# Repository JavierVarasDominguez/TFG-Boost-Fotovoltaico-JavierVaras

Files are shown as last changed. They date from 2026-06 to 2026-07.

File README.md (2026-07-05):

# Diseño y estudio de un convertidor DC-DC Boost para carga de vehículos eléctricos a partir de energía fotovoltaica

Repositorio asociado al Trabajo Fin de Grado:

**Diseño y estudio de un convertidor DC-DC Boost para carga de vehículos eléctricos a partir de energía fotovoltaica**
**Autor:** Javier Varas Domínguez
**Titulación:** Grado en Ingeniería Electrónica Industrial y Automática
**Universidad:** Universidad de Cantabria
**Tutor:** Francisco Javier Díaz Rodríguez
**Curso:** 2025/2026

---

## Descripción del proyecto

Este proyecto tiene como objetivo el diseño, simulación y validación de un convertidor DC-DC tipo Boost aplicado a un sistema de carga de baterías de vehículos eléctricos alimentado mediante energía fotovoltaica.

El sistema parte de una instalación fotovoltaica residencial de aproximadamente 2,4 kW, formada por seis módulos conectados en serie. La tensión generada por el campo fotovoltaico se eleva mediante un convertidor Boost hasta un nivel adecuado para la carga de baterías de vehículos eléctricos.

Además del diseño teórico del convertidor, se ha desarrollado un modelo de simulación en MATLAB/Simulink, se ha implementado un algoritmo MPPT basado en el método de perturbación y observación, y se ha construido un prototipo experimental a escala reducida controlado mediante ESP32S.

---

## Objetivos principales

* Diseñar un convertidor DC-DC tipo Boost para una aplicación fotovoltaica orientada a la carga de vehículos eléctricos.
* Dimensionar los principales componentes de la etapa de potencia.
* Simular el comportamiento del sistema en MATLAB/Simulink.
* Implementar un algoritmo MPPT para mejorar el aprovechamiento de la energía disponible.
* Diseñar y fabricar una PCB para el prototipo experimental.
* Validar el funcionamiento del sistema mediante un prototipo a escala reducida.

---

## Estructura del repositorio

```text
TFG-Boost-Fotovoltaico-JavierVaras/
│
├── Simulink_Matlab/
│   ├── 04_Simulaciones_Convertidor/
│   └── Prototipo/
│
├── Codigos_Control_ESP32/
│
├── KiCad_Prototipo/
│
├── Documentacion_TFG/

```

### Simulink_Matlab

Contiene los modelos de simulación desarrollados en MATLAB/Simulink.
Incluye las simulaciones del convertidor Boost, el funcionamiento con ciclo de trabajo fijo, la implementación del algoritmo MPPT y la validación del prototipo experimental.

### Codigos_Control_ESP32

Incluye los códigos utilizados para el control del prototipo mediante ESP32S.
Se recogen tanto las pruebas de generación PWM como la implementación del algoritmo MPPT.

### KiCad_Prototipo

Contiene los archivos relacionados con el diseño electrónico del prototipo.
Incluye el esquemático, el diseño de la PCB y los archivos necesarios para documentar la placa desarrollada.

### Documentacion_TFG

Carpeta destinada a recoger la memoria del Trabajo Fin de Grado y documentación complementaria.

### Resultados_Experimentales

Incluye capturas, medidas de laboratorio y fotografías relacionadas con las pruebas del prototipo experimental.

---

## Herramientas utilizadas

* MATLAB/Simulink
* KiCad
* Arduino IDE
* ESP32S
* Osciloscopio y fuente de alimentación de laboratorio
* Instrumentación básica de medida

---

## Contenido técnico del proyecto

El trabajo incluye:

* Estudio del funcionamiento del convertidor Boost en modo de conducción continua.
* Cálculo del ciclo de trabajo para distintos valores de tensión de entrada.
* Dimensionado de la inductancia y condensadores.
* Selección de MOSFET, diodo, driver de puerta y componentes auxiliares.
* Simulación del convertidor en lazo abierto.
* Implementación del algoritmo MPPT mediante perturbación y observación.
* Análisis ante variaciones de irradiancia.
* Diseño de un prototipo experimental a escala reducida.
* Diseño y fabricación de la PCB.
* Validación experimental mediante medidas de laboratorio.

---

## Prototipo experimental

El prototipo se ha desarrollado a escala reducida para validar el funcionamiento básico del convertidor y del sistema de control.
La etapa de potencia se ha diseñado como un convertidor Boost alimentado a baja tensión, controlado mediante una señal PWM generada por un ESP32S.

El objetivo del prototipo no es replicar la potencia del sistema fotovoltaico completo, sino comprobar de forma práctica el comportamiento del convertidor, la generación de la señal de control y la respuesta del algoritmo MPPT.

---

## Nota

Este repositorio se ha creado como complemento a la memoria del Trabajo Fin de Grado.
Los archivos incluidos tienen finalidad académica y sirven para documentar el desarrollo del proyecto, las simulaciones realizadas, el diseño de la PCB y las pruebas experimentales llevadas a cabo.

---

## Autor

**Javier Varas Domínguez**
Grado en Ingeniería Electrónica Industrial y Automática
Universidad de Cantabria

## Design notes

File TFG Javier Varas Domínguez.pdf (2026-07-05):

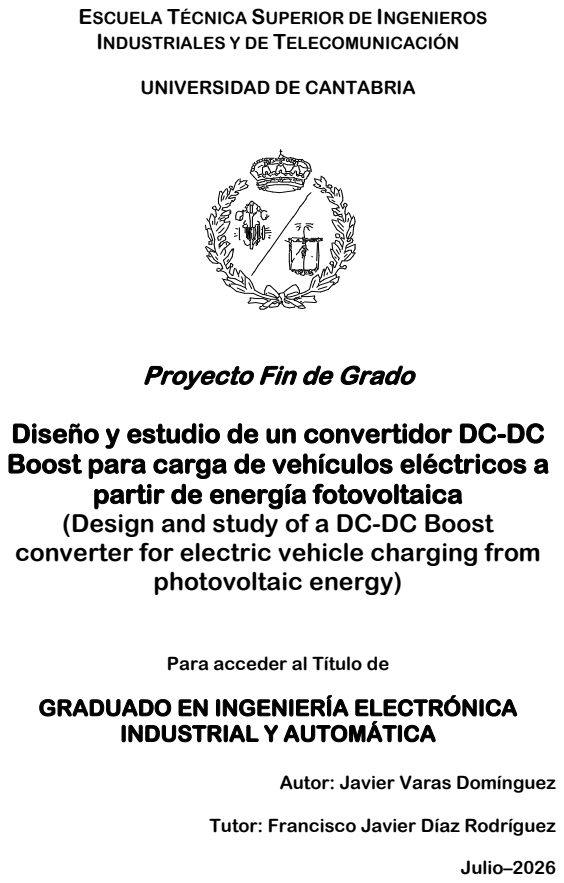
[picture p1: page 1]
photovoltaic energy); INDUSTRIAL Y AUTOMÁTICA; Julio–2026

ESCUELA TÉCNICA SUPERIOR DE INGENIEROS
INDUSTRIALES Y DE TELECOMUNICACIÓN

UNIVERSIDAD DE CANTABRIA

Proyecto Fin de Grado

Diseño y estudio de un convertidor DC-DC
Boost para carga de vehículos eléctricos a

partir de energía fotovoltaica
(Design and study of a DC-DC Boost
converter for electric vehicle charging from

Para acceder al Título de

GRADUADO EN INGENIERÍA ELECTRÓNICA

Autor: Javier Varas Domínguez

Tutor: Francisco Javier Díaz Rodríguez

Javier Varas Domínguez | Carga fotovoltaica de VE mediante convertidor Boost

Quiero dedicar este Trabajo de Fin de Grado:

A mi tutor, Francisco Javier Díaz, por su guía, paciencia y apoyo en la elaboración de este

proyecto. Por dirigir y acompañarme en cada reto técnico.

A mi familia, por su ayuda incondicional en cada paso del camino y por proporcionarme

siempre todo lo necesario para llegar hasta aquí, apoyándome en todo momento.

A mis compañeros de clase, por hacer que cada hora de clase y de estudio fueran mucho

más amenas, compartiendo momentos inolvidables que me acompañarán siempre.

## RESUMEN

En este trabajo se propone el diseño, simulación y validación de un convertidor DC-DC tipo

Boost aplicado a un sistema de carga de baterías de vehículos eléctricos alimentado mediante

energía fotovoltaica. El sistema parte de una instalación fotovoltaica residencial de

aproximadamente 2,4 kW, cuya tensión de operación debe elevarse hasta un valor adecuado

para la carga. Se dimensiona el convertidor a partir de las especificaciones del sistema y se

estudia su funcionamiento en conducción continua.

Una vez diseñado el convertidor, se verifica su comportamiento mediante simulación en

MATLAB/Simulink. En primer lugar, se analiza el sistema con ciclo de trabajo fijo y,

posteriormente, se incorpora un algoritmo MPPT basado en el método de perturbación y

observación para mejorar el aprovechamiento de la energía disponible. También se estudia

la respuesta ante variaciones de irradiancia y se considera la estrategia de carga CC-CV

como referencia teórica para la batería. Finalmente, se desarrolla un prototipo experimental

a escala reducida controlado mediante un ESP32S y se documenta el esquemático y diseño

de la PCB.

## ABSTRACT

This project proposes the design, simulation, and validation of a Boost DC-DC converter

applied to an electric vehicle battery charging system powered by photovoltaic energy. The

system is based on a residential photovoltaic installation with an approximate power rating of

2.4 kW, whose operating voltage must be increased to a suitable level for battery charging.

The converter is sized according to the system specifications, and its operation under

continuous conduction mode is analyzed.

Once the converter has been designed, its performance is verified through simulations in

MATLAB/Simulink. First, the system is analyzed using a fixed duty cycle, after which an MPPT

algorithm based on the perturb-and-observe method is incorporated to improve the utilization

of the available energy. The system response to variations in solar irradiance is also studied,

and the CC-CV charging strategy is considered as a theoretical reference for the battery.

Finally, a reduced-scale experimental prototype controlled by an ESP32S is developed, and

the schematic and PCB design are documented.

## ÍNDICE DE DOCUMENTACIÓN

DOCUMENTO 1: MEMORIA | 6
DOCUMENTO 2: ANEXOS | 100
DOCUMENTO 3: PLANOS | 108
DOCUMENTO 4: PLIEGO DE CONDICIONES | 115
DOCUMENTO 5: PRESUPUESTO | 123
BIBLIOGRAFÍA | 131

# DOCUMENTO 1: MEMORIA

## ÍNDICE DE LA MEMORIA

8.5.2. Selección de los condensadores | 85
8.5.3. Selección del MOSFET | 85
8.5.4. Selección del diodo | 86
8.5.5. Selección del driver de puerta y ESP32S | 86
8.5.6. Selección de la carga y montaje | 87
8.6. MONTAJE Y PRIMERAS PRUEBAS DEL PROTOTIPO | 88
8.6.1. Montaje del prototipo | 88
8.6.2. Comprobación de la etapa de control | 90
8.6.3. Pruebas del convertidor en lazo abierto | 91
8.6.4. Prueba experimental del algoritmo MPPT | 95

### 9. CONCLUSIONES | 97

9.1. CONCLUSIONES GENERALES | 97
9.2. TRABAJOS FUTUROS | 98

## ÍNDICE DE FIGURAS

Figura 3. Esquema del sistema propuesto de carga de vehículo eléctrico alimentado

Figura 4. Irradiancia media mensual en Santander obtenida a partir de la herramienta

Figura 10. Medida del rizado de corriente de la inductancia en régimen permanente .54

Figura 21. Trayectoria corriente-tensión del generador fotovoltaico para una irradiancia de 1000 W/m²

Figura 22. Trayectoria corriente-tensión del generador fotovoltaico para una irradiancia de 600 W/m²

Figura 23. Modelo de Simulink del convertidor Boost adaptado al prototipo experimental

Figura 25. Corriente en la inductancia del prototipo en Simulink | 81
Figura 26. Modelo de Simulink con control externo mediante ESP32S | 82
Figura 27. Evolución del ciclo de trabajo calculado por el ESP32S | 83
Figura 28. Tensión de salida del prototipo con control mediante ESP32S | 83
Figura 29. Montaje experimental del convertidor Boost a escala reducida | 88

Figura 30. Placa de circuito impreso fabricada para el prototipo del convertidor Boost y
modelo 3D de la placa en KiCad | 89
Figura 31. Señal PWM generada por el ESP32S | 90

Figura 32. Comparación entre la señal PWM del ESP32S y la salida del driver TC4422.90

Figura 33. Tensión de puerta del MOSFET respecto a masa | 91

Figura 34. Tensión de salida del convertidor y señal PWM para un ciclo de trabajo cercano
al 50 % | 92
Figura 35. Detalle de las oscilaciones presentes en la tensión de salida | 93

Figura 36. Tensión entre puerta y fuente del MOSFET durante la prueba de lazo abierto
| 94

Figura 37. Corriente de la inductancia durante el funcionamiento en lazo abierto. ......95

Figura 38. Montaje experimental del prototipo con el divisor de tensión y la resistencia shunt
conectados | 96

## ÍNDICE TABLAS

## SÍMBOLOS Y ABREVIATURAS

Hz | Hercios, unidad de frecuencia.

W Vatios, unidad de potencia.

V Voltio, unidad de tensión eléctrica.

A Amperio, unidad de corriente eléctrica.

Ω | Ohmio, unidad de resistencia eléctrica.

F Faradio, unidad de capacidad eléctrica.

H Henrio, unidad de inductancia.

ºC | Grados Celsius, unidad de temperatura.
W/m² | Vatios por metro cuadrado, unidad de irradiancia.
DC | Corriente continua.
AC | Corriente alterna.
DC-DC | Conversión de corriente continua a corriente continua.
FV | Fotovoltaico.
AM | Air mass o Masa de aire.
VE | Vehículo eléctrico.
Boost | Convertidor elevador de tensión.
MPPT | Maximum Power Point Tracking o seguimiento del punto de máxima potencia.
MPP | Maximum Power Point o punto de máxima potencia.
P&O | Perturb and Observe o método de perturbación y observación.
CC-CV | Estrategia de carga a corriente constante y tensión constante.
PWM | Modulación por ancho de pulso.
CCM | Modo de conducción continua.
DCM | Modo de conducción discontinua.
STC | Condiciones estándar de medida.
I-V | Curva corriente-tensión de un módulo fotovoltaico.
P-V | Curva potencia-tensión de un módulo fotovoltaico.

MOSFET | Metal-Oxide-Semiconductor Field-Effect Transistor o transistor de efecto de campo metal-óxido-semiconductor.
SiC | Carburo de silicio.
GaN | Nitruro de galio.
ESP32S | Microcontrolador utilizado para el control del prototipo.
GPIO | General Purpose Input/Output o entrada/salida de propósito general.
THT | Through-Hole Technology o tecnología de montaje con terminal pasante.
PCB | Printed Circuit Board o placa de circuito impreso.
ESR | Resistencia serie equivalente.
MATLAB | Entorno de cálculo y programación utilizado en el proyecto.
Simulink | Entorno de simulación utilizado para modelar el sistema.
KiCad | Software utilizado para el diseño del esquemático y de la PCB.

## 1. Introducción

El uso de vehículos eléctricos ha crecido de forma notable debido a la necesidad de

reducir las emisiones contaminantes y avanzar hacia un modelo energético más sostenible.

Las energías renovables han ido ganando importancia, especialmente en sistemas de

autoconsumo, donde la energía solar fotovoltaica se ha convertido en una de las opciones

más utilizadas.

La combinación de generación fotovoltaica y sistemas de carga de vehículos eléctricos

resulta especialmente interesante, sin embargo, la integración entre ambos no es directa. La

energía generada por los paneles solares depende de factores como la irradiancia y la

temperatura lo que provoca variaciones en la tensión y en la potencia disponible.

Para poder aprovechar la energía fotovoltaica de forma eficiente es necesario emplear

sistemas electrónicos que permitan adaptar las condiciones del generador a las condiciones

de la carga. En este sentido los convertidores DC-DC juegan un papel fundamental. En

particular, el convertidor tipo Boost se utiliza cuando es necesario elevar la tensión

proporcionada por el sistema fotovoltaico, como ocurre en aplicaciones de carga de baterías

de vehículos eléctricos.

Para maximizar la energía extraída del panel fotovoltaico se utilizan algoritmos de

seguimiento del punto de máxima potencia o MPPT (Maximum Power Point Tracking), que

permiten ajustar el punto de funcionamiento del sistema en función de las condiciones

ambientales.

En este trabajo se plantea el diseño, análisis y validación de un convertidor DC-DC tipo

Boost aplicado a un sistema fotovoltaico orientado a la carga de baterías de vehículo eléctrico.

Se realizará un estudio teórico del sistema, el diseño del convertidor, la simulación de su

funcionamiento y el desarrollo de un prototipo experimental a escala reducida que permita

verificar el comportamiento del sistema y del algoritmo MPPT implementado.

### 1.1. Descripción del sistema

Se plantea el diseño de un sistema de carga de baterías de vehículos eléctricos

alimentado mediante energía solar fotovoltaica y pensado para una instalación residencial de

pequeña escala.

El sistema está formado por un campo fotovoltaico compuesto por seis módulos

conectados en serie, con una potencia total aproximada de 2,4 kW. Esta configuración

proporciona una tensión de operación en el punto de máxima potencia del orden de 220-250

V, que resulta inferior a la tensión requerida para la carga de la batería de un vehículo eléctrico, normalmente situada entre 350 y 400 V, llegando incluso a niveles de 800 V para

sistemas de carga rápida.

Debido a esta diferencia de niveles de tensión es necesario emplear un convertidor

DC-DC tipo Boost, que actúa como etapa principal de potencia y permite elevar la tensión del

generador hasta el nivel requerido para la carga de la batería.

Para mejorar el aprovechamiento de la energía generada, el sistema incorpora un

algoritmo de seguimiento del punto de máxima potencia (MPPT), que ajusta el punto de

operación en función de las condiciones ambientales. En el lado de la salida, la carga de la

batería se realiza siguiendo una estrategia de corriente constante-tensión constante (CC-CV),

tal y como es habitual en este tipo de aplicaciones.

### 1.2. Objetivos del proyecto

El objetivo principal de este trabajo es el diseño y análisis de un convertidor DC-DC

tipo Boost alimentado por un sistema fotovoltaico residencial, orientado a la carga de baterías

de vehículos eléctricos.

Se realiza el estudio del funcionamiento del convertidor, su dimensionado y la estimación

de sus principales parámetros eléctricos. Asimismo, se implementa un algoritmo de

seguimiento del punto de máxima potencia (MPPT) para optimizar la energía extraída del

generador fotovoltaico. Finalmente, se valida el sistema mediante simulación y mediante la

construcción de un prototipo experimental a escala reducida que permita comprobar el

correcto funcionamiento del convertidor y del algoritmo de control implementado.

## 2. Fundamentos y estado del arte

Se presentan los fundamentos teóricos necesarios para el desarrollo del sistema

propuesto, así como una revisión del estado del arte relacionado con la integración de

sistemas fotovoltaicos en aplicaciones de carga para vehículos eléctricos.

### 2.1. Generación fotovoltaica

Se basa en la conversión directa de la energía solar en energía eléctrica mediante el

efecto fotovoltaico que tiene lugar en materiales semiconductores principalmente silicio.

Cuando la radiación solar incide sobre la célula fotovoltaica se genera una diferencia de

potencial que permite la circulación de corriente eléctrica en un circuito externo, constituyendo

la base de la generación de energía en el módulo fotovoltaico [1].

El comportamiento de un generador fotovoltaico depende fundamentalmente de las

condiciones ambientales, especialmente de la irradiancia solar y de la temperatura. Estas

variables influyen directamente en la tensión y en la corriente generadas lo que hace

necesario su estudio para el correcto diseño del sistema.

### 2.1.1. Curva I-V y punto de máxima potencia

El comportamiento eléctrico de un módulo fotovoltaico se representa mediante su curva

corriente-tensión (curva I-V), que describe la relación entre la corriente suministrada y la

tensión en sus bornes para unas condiciones determinadas de irradiancia y temperatura [2].

En esta curva se definen parámetros fundamentales como la corriente de cortocircuito

(Isc), la tensión a circuito abierto (Voc), la tensión en el punto de máxima potencia (Vmp) y la

corriente en dicho punto (Imp). El punto de máxima potencia (MPP, Maximum Power Point) es

aquel en el que el producto de la tensión y la corriente alcanza su valor máximo.

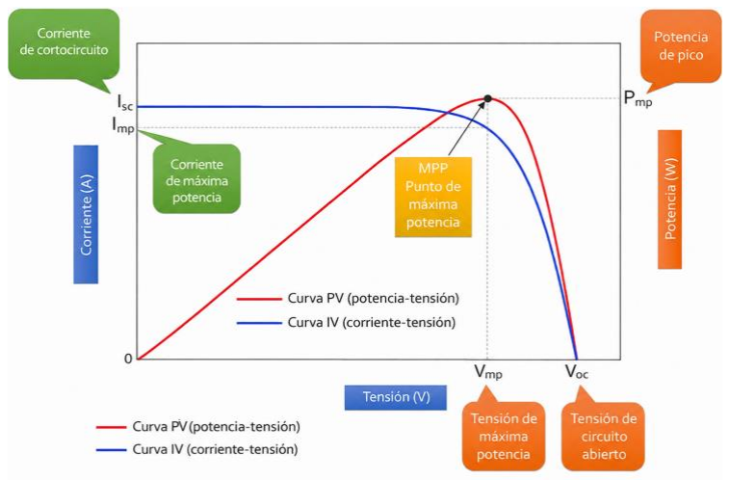
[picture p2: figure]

Figura 1. Curvas I-V y P-V de un módulo fotovoltaico [3]

Los valores nominales de estos parámetros se especifican bajo condiciones estándar de medida (STC, Standard Test Conditions), definidas por una irradiancia de 1000 W/m²
, una

temperatura de célula de 25ºC y una masa de aire AM 1.5, sin depender de la localización

geográfica del sistema [2].

En condiciones reales de operación tanto la irradiancia como la temperatura varían

continuamente, lo que provoca desplazamientos en la curva I-V. Un aumento de la irradiancia

produce un incremento casi proporcional de la corriente generada mientras que la tensión

varía en menor medida. Por el contrario, un aumento de la temperatura provoca una

disminución de la tensión (especialmente de Voc y Vmp) y un ligero incremento de la corriente,

reduciendo la potencia máxima disponible [2][4].

Debido a esta variabilidad, el generador fotovoltaico no opera de forma natural en su punto

de máxima potencia. En aplicaciones como la carga de vehículos eléctricos es necesario

emplear sistemas electrónicos de potencia junto con algoritmos de control que permitan

ajustar el punto de operación del sistema y maximizar la energía extraída del generador [5].

### 2.2. Convertidor DC-DC tipo Boost

Los convertidores DC-DC son circuitos electrónicos de potencia que permiten adaptar los

niveles de tensión y corriente entre una fuente de energía y una carga. Se utilizan

ampliamente en sistemas de energías renovables, donde la tensión de entrada no es

constante y es necesario ajustarla a los requisitos del sistema [6].

Existen diferentes tipos de convertidores DC-DC entre los que destacan: el convertidor

reductor (Buck), el convertidor elevador (Boost) y el convertidor Buck-Boost. La elección de

una u otra tipología depende principalmente de la relación entre la tensión de entrada y la

tensión de salida que se necesita obtener.

En este trabajo, el generador fotovoltaico proporciona una tensión en el punto de máxima

potencia del orden de 220-250 V, mientras que la batería de un vehículo eléctrico requiere

una tensión comprendida entre 350 y 400 V. Esto implica que es necesario elevar la tensión,

por lo que el uso de un convertidor tipo Boost resulta una solución adecuada.

Frente a otras alternativas, el convertidor Boost presenta varias ventajas en esta

aplicación. Por un lado, permite elevar la tensión de forma directa sin necesidad de invertir su

polaridad y, por otro, su estructura es relativamente sencilla, lo que facilita tanto su control

como su implementación práctica. Además, en este sistema no es necesario reducir la tensión

en ningún momento, por lo que el uso de tipologías como el Buck o el Buck-Boost no aportaría

beneficios claros y sí añadiría complejidad.

El convertidor Boost está formado por un interruptor eléctrico controlado (normalmente un

MOSFET), un diodo, una inductancia y un condensador de salida. Su funcionamiento se basa

en la transferencia de energía desde la inductancia hacia la carga mediante un proceso de

conmutación.

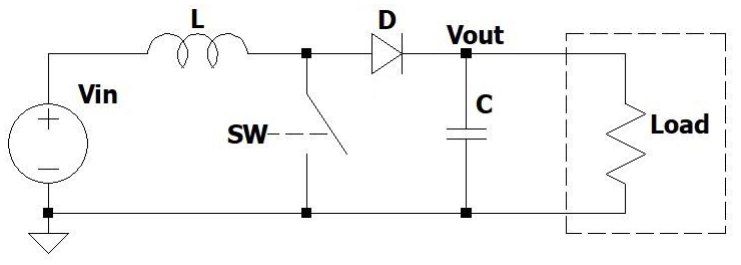
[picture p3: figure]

Figura 2. Esquema del convertidor Boost [7]

Cuando el interruptor principal está en conducción, la inductancia almacena energía

procedente de la fuente de entrada. En esta fase el diodo se encuentra bloqueado y la carga

es alimentada por el condensador de salida. Cuando el interruptor se abre, la inductancia

libera la energía almacenada, sumándola a la tensión de entrada y transfiriéndola a la carga

a través del diodo, lo que permite obtener una tensión de salida superior a la de entrada [6][8].

El convertidor puede operar en modo de conducción continua (CCM), en el que la

corriente que circula por la inductancia no llega a cero, o en modo de conducción discontinua

(DCM), donde dicha corriente alcanza el valor cero antes de finalizar el periodo.

En aplicaciones de potencia media, como la carga de baterías de vehículos eléctricos, se

prefiere el funcionamiento en CCM debido a su menor rizado de corriente, a sus menores

esfuerzos en los dispositivos y a su comportamiento dinámico más predecible [8].

En condiciones ideales y régimen estacionario la relación entre la tensión de salida y la

tensión de entrada viene dada por:

Vout

Vin

=

1
1 − D

(1)

Donde D es el ciclo de trabajo del interruptor, definido como la fracción del periodo de

conmutación durante la cual el interruptor permanece en conducción. Por tanto, este

parámetro varía entre un valor mínimo cercano a cero y un valor máximo de uno.

Al aumentar el ciclo de trabajo la tensión de salida también aumenta, lo que permite

adaptar la tensión del generador fotovoltaico a la requerida por la batería del vehículo

eléctrico, manteniendo el funcionamiento dentro de un rango adecuado.

### 2.2.1. Aspectos prácticos del convertidor Boost

El análisis anterior describe el funcionamiento ideal del convertidor. En la práctica es

necesario tener en cuenta ciertos factores que influyen en su comportamiento real.

Uno de los más importantes es el rizado de corriente en la inductancia. Esta corriente no

es constante, sino que presenta pequeñas variaciones alrededor de su valor medio debido al

proceso de conmutación. El valor de este rizado depende del tamaño de la inductancia y de

la frecuencia de conmutación y debe mantenerse dentro de unos límites para evitar un

funcionamiento inestable o un aumento excesivo de pérdidas [8].

La tensión de salida tampoco es completamente constante, sino que presenta un pequeño

rizado debido a la carga y descarga del condensador. Este rizado de tensión depende del

valor del condensador y de la corriente suministrada a la carga, por lo que su correcta

selección es importante para garantizar una tensión de salida adecuada.

En un convertidor real existen pérdidas asociadas a los componentes. Estas pérdidas se

deben principalmente a la resistencia de los elementos, así como a los procesos de

conmutación del interruptor. Como consecuencia, la eficiencia del convertidor es siempre

inferior al caso ideal [6].

Por último, el ciclo de trabajo no puede tomar cualquier valor. Valores muy altos implican

mayores esfuerzos eléctricos en los componentes y pueden dificultar el control del sistema.

En el diseño del convertidor se busca trabajar en un rango de funcionamiento razonable, que

permita garantizar tanto la eficiencia como la estabilidad.

### 2.3. Algoritmo MPPT

El seguimiento del punto de máxima potencia MPPT (Maximum Power Point Tracking) es

una técnica de control implementada en los sistemas fotovoltaicos para garantizar que la

placa opere en el punto de máxima potencia disponible en cada instante [9]. Debido a la

naturaleza no lineal corriente-tensión (I-V) de los sistemas fotovoltaicos, dicho punto depende

de la irradiancia y la temperatura, por lo que su valor cambia a lo largo del día y no puede

considerarse fijo [2] [9].

La potencia suministrada por el generador se expresa como:

P = V ∙ I | (2)

El punto de máxima potencia se alcanza cuando la derivada de la potencia respecto a la

tensión se anula:

dP
dV = 0 | (3)

Desarrollando la expresión anterior:

dP
dV = I + V

dI
dV | (4)

Por tanto, en MPP se cumple que:

I + V

dI
dV = 0 | (5)

Esta condición constituye la base teórica de los principales algoritmos MPPT [9],[10].

En el sistema propuesto en este trabajo el algoritmo MPPT no actúa como una etapa

independiente, sino que se implementa como parte del control del convertidor DC-DC tipo

Boost, modificando el ciclo de trabajo. El convertidor altera la impedancia vista por el

generador fotovoltaico, desplazando el punto de máxima potencia sobre la curva I-V hasta

situarlo en las proximidades del punto de máxima potencia.

### 2.3.1. Principales métodos MPPT

Los algoritmos más empleados para el seguimiento del punto de máxima potencia en

sistemas fotovoltaicos son: el seguimiento de tensión constante CVT (Constant Voltage

Tracking), el método de perturbación y observación P&O (Perturb and Observe) y el método

de conductancia incremental INC (Incremental Conductance).

- Seguimiento de tensión constante (CVT): Se basa en mantener la tensión del

generador próxima a un valor estimado del punto de máxima potencia. Es sencillo de

implementar y requiere bajo esfuerzo computacional, aunque su precisión es limitada

cuando varía mucho la irradiancia o la temperatura.

- Perturbación y observación (P&O): Introduce pequeñas variaciones en el punto de

operación, habitualmente mediante el ajuste del ciclo de trabajo de un convertidor, y

evalúa el efecto sobre la potencia generada. Si la potencia aumenta, continúa en la

misma dirección, si disminuye, invierte el sentido del ajuste. Es un método simple y

ampliamente utilizado, aunque presenta pequeñas oscilaciones alrededor del MPP en

régimen estacionario.

- Conductancia incremental (INC): Se basa en la condición matemática del punto de

máxima potencia, comparando la conductancia instantánea I/V con la conductancia incremental dI/dV. Ofrece mayor precisión frente a cambios rápidos de irradiancia, a

costa de una mayor complejidad de implementación [11].

En este trabajo se prioriza un algoritmo robusto para aplicaciones de potencia moderada,

por lo que el método P&O se considera una opción adecuada para su implementación en el

convertidor Boost.

### 2.4. Estrategia de carga CC-CV

En el apartado anterior se ha descrito el uso de algoritmos MPPT para maximizar la

potencia extraída del generador fotovoltaico. Sin embargo, en aplicaciones de carga de

baterías, no solo es importante optimizar la obtención de energía, sino también garantizar que

el proceso de carga se realice de forma segura y adecuada a las características del sistema

de almacenamiento [12].

En el caso de baterías de vehículos eléctricos, el método de carga más habitual es el

denominado corriente constante-tensión constante (CC-CV), que permite controlar tanto la

corriente como la tensión aplicada durante las distintas etapas del proceso de carga [12][13].

### 2.4.1. Principios de funcionamiento

El método CC-CV o perfil de carga se divide en dos fases principales:

- Fase de corriente constante (CC): Durante esta etapa inicial, la batería se carga

manteniendo una corriente aproximadamente constante, lo que permite una

transferencia de energía rápida y eficiente. En esta fase la tensión de la batería

aumenta progresivamente a medida que se incrementa su estado de carga [12].

- Fase de tensión constante (CV): Una vez alcanzada la tensión nominal máxima de

la batería, el sistema mantiene dicha tensión constante y reduce progresivamente la

corriente de carga. Esta etapa evita la sobrecarga y permite completar el proceso de

forma controlada [13].

Esta estrategia es ampliamente utilizada en baterías de ion-litio pues permite maximizar

la vida útil del sistema y garantizar condiciones seguras de operación [13],[14].

### 2.4.2. Integración con el sistema fotovoltaico

En el sistema propuesto la estrategia de carga CC-CV se implementa mediante el control

del convertidor DC-DC tipo Boost, que actúa como interfaz entre el generador fotovoltaico y

la batería.

Durante la fase de corriente constante el sistema debe regular la corriente suministrada a

la batería, mientras que en la fase de tensión constante el objetivo pasa a ser el control de la

tensión en los bornes de esta. En ambos casos el convertidor ajusta su ciclo de trabajo para

cumplir las condiciones de carga requeridas.

La integración del control CC-CV con el algoritmo MPPT introduce un compromiso en la

operación del sistema. Mientras que el MPPT busca maximizar la potencia extraída del

generador fotovoltaico, el control de carga impone restricciones en corriente o tensión para

proteger la batería [14].

El sistema debe ser capaz de priorizar uno u otro objetivo en función del estado de carga

de batería. En condiciones normales el sistema operará en modo MPPT, mientras que en

situaciones en las que se alcancen los límites de corriente o tensión de la batería, el control

CC-CV prevalecerá sobre la maximización de la potencia.

### 2.5. Estado actual de la tecnología

En los últimos años el desarrollo de los vehículos eléctricos ha ido acompañado de un

crecimiento en las tecnologías de carga, especialmente aquellas basadas en energías

renovables. Dentro de este contexto la integración de sistemas fotovoltaicos en instalaciones

de autoconsumo para la carga de vehículos eléctricos se ha convertido en una línea de trabajo

bastante habitual, tanto a nivel industrial como en investigación.

En la práctica muchos de estos sistemas utilizan convertidores DC-DC como etapa

intermedia entre el generador fotovoltaico y la batería. Aunque existen distintas tipologías, el

convertidor Boost sigue siendo una de las soluciones más utilizadas cuando se necesita

elevar la tensión de forma sencilla, debido a que su funcionamiento es bien conocido y a que

permite obtener buenos rendimientos sin necesidad de un control excesivamente complejo.

En aplicaciones reales este tipo de convertidores puede alcanzar eficiencias superiores al

90% en condiciones adecuadas de funcionamiento [15].

También en los últimos años ha habido avances significativos en los dispositivos

electrónicos utilizados en estos sistemas. En particular los semiconductores de nueva

generación, como los basados en carburo de silicio (SiC) o nitruro de galio (GaN), están empezando a sustituir a los dispositivos tradicionales en muchas aplicaciones. Estos

materiales permiten trabajar en frecuencias más altas y reducen las pérdidas de conmutación,

lo que se traduce en equipos más eficientes y, en algunos casos, más compactos [16]. Aun

así, su uso todavía está más extendido en aplicaciones de mayor potencia o en entornos

industriales.

En investigación se están planteando nuevas formas de integrar directamente los

sistemas fotovoltaicos en la carga de vehículos eléctricos. Algunas propuestas buscan reducir

el número de etapas de conversión energética para mejorar la eficiencia global del sistema.

Sin embargo, estas soluciones suelen requerir un control más complejo y no siempre son

fáciles de implementar en sistemas reales [17].

Aunque existen tecnologías más avanzadas en desarrollo, las soluciones basadas en

convertidores DC-DC convencionales siguen siendo una opción muy válida. En particular el

convertidor Boost continúa utilizándose ampliamente en sistemas de potencia media, como

el planteado en este trabajo, debido a su simplicidad, su robustez y la facilidad con la que se

puede integrar con algoritmos de control como el MPPT.

En la Figura 3 se muestra el esquema del sistema electrónico que se propone en este

trabajo.

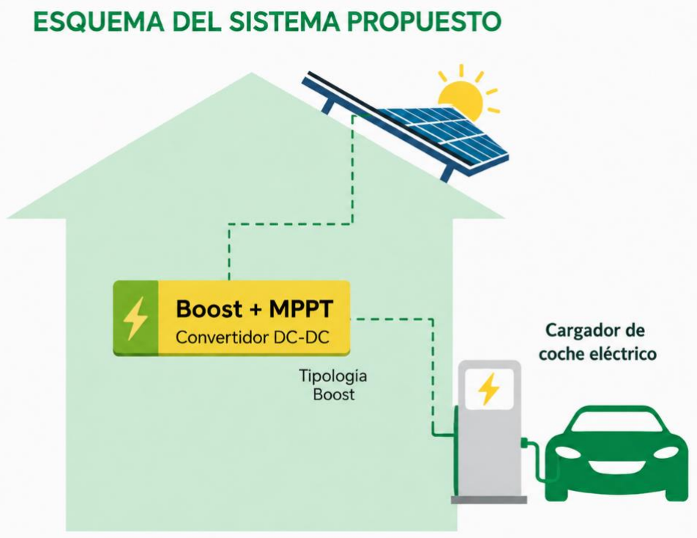
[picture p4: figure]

Figura 3. Esquema del sistema propuesto de carga de vehículo eléctrico alimentado mediante

energía fotovoltaica.

## 3. Especificaciones de diseño

En este capítulo se definen las condiciones de partida del sistema propuesto, así como

los parámetros eléctricos y las hipótesis de funcionamiento que servirán de base para el

diseño del convertidor en los capítulos posteriores.

Se establecen tanto las características del generador fotovoltaico como las condiciones de

operación y los requisitos del sistema de carga, con el objetivo de delimitar el marco de diseño

del sistema.

### 3.1. Parámetros eléctricos del sistema

El sistema propuesto se ha dimensionado para una potencia aproximada de 2,4 kW,

correspondiente a un campo fotovoltaico conformado por seis módulos conectados en serie.

Esta elección busca un equilibrio entre la potencia disponible, el coste de la instalación y el

espacio que suele haber en una vivienda.

En un entorno doméstico no es habitual disponer de grandes superficies para instalar

paneles, por lo que el número de módulos debe ser razonable. Se ha optado por seis paneles

que permiten obtener una potencia suficiente para aplicaciones de carga de vehículos

eléctricos sin que la instalación resulte excesiva en tamaño.

Desde el punto de vista económico esta configuración también resulta interesante porque

reduce el número de módulos necesarios y, por tanto, el coste inicial del sistema. De este

modo, se consigue un compromiso entre simplicidad, coste y prestaciones adecuadas para

una instalación de tipo residencial.

Para el dimensionado del sistema se ha considerado un módulo fotovoltaico

representativo de 400W, valor típico en paneles comerciales actuales. Sus características

eléctricas bajo condiciones estándar (STC) son de una tensión de circuito abierto en el rango

de 40-48 V y una corriente en el punto de máxima potencia del orden de 10-11 A [18].

A partir de estos valores, el campo fotovoltaico completo presenta aproximadamente las

siguientes magnitudes:

- Potencia total: 2,4 kW
- Tensión en circuito abierto: ≈ 270 V
- Corriente de operación: ≈ 10-11 A

Estas condiciones hacen necesaria la utilización de un convertidor DC-DC tipo Boost,

pues la tensión proporcionada por el generador fotovoltaico es inferior a la requerida por la

batería de un vehículo eléctrico que normalmente se sitúa en el rango de 350-400 V.

El convertidor debe ser capaz de elevar la tensión de entrada hasta el nivel requerido,

manteniendo al mismo tiempo un funcionamiento eficiente y estable dentro del rango de

operación del sistema.

### 3.2. Condiciones de funcionamiento

El sistema se plantea para su posible instalación en un entorno residencial del norte de

España, concretamente en la zona de Santander. En este tipo de ubicaciones la generación

fotovoltaica está bastante condicionada por la climatología. Es habitual encontrar días con

alta radiación solar seguidos de otros con alta nubosidad.

Esta variabilidad hace que la potencia generada por el campo fotovoltaico no sea

constante, sino que pueda cambiar de forma notable a lo largo del día. Por este motivo, el

sistema debe ser capaz de adaptarse a diferentes condiciones de funcionamiento sin perder

estabilidad.

De cara al diseño, se consideran valores de irradiancia comprendidos aproximadamente entre 400 y 1000 W/m²
[19]. El valor superior corresponde a condiciones cercanas al estándar

(STC), mientras que los valores más bajos representan situaciones de menor radiación

debidas a nubosidad o condiciones atmosféricas desfavorables.

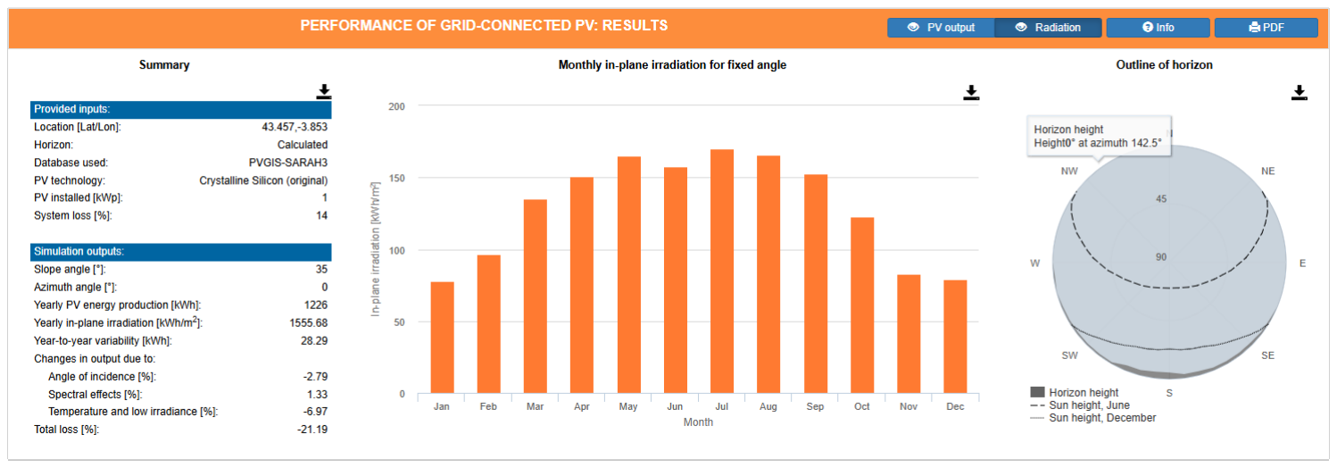
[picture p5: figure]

Figura 4. Irradiancia media mensual en Santander obtenida a partir de la herramienta PVGIS [20]

Como se observa en la figura 4 la irradiancia presenta una variación significativa a lo

largo del año, con valores más elevados en los meses de verano y valores inferiores en

invierno, lo que influye directamente en la potencia generada por el sistema fotovoltaico.

En cuanto a la temperatura se toma como referencia la condición estándar de 25ºC

correspondiente a la temperatura de la célula en condiciones STC. Sin embargo, en

condiciones reales de funcionamiento la temperatura del panel fotovoltaico puede variar en

un rango más amplio, típicamente entre 0ºC y 60ºC, dependiendo de las condiciones

ambientales y de la radiación solar. Estas variaciones afectan principalmente a la tensión del

generador fotovoltaico, produciendo una disminución de esta a medida que aumenta la

temperatura [2],[19].

Desde el punto de vista del sistema de carga se considera una batería de vehículo

eléctrico con una tensión nominal entre 350 y 400 V. Este tipo de baterías suele cargarse

siguiendo una estrategia de corriente constante-tensión constante (CC-CV), ampliamente

utilizada en este tipo de aplicaciones. Dicha estrategia se tendrá en cuenta únicamente a nivel

teórico, considerando cómo condiciona el funcionamiento del sistema, pero sin profundizar

en su implementación.

El convertidor DC-DC tipo Boost debe de ser capaz de operar correctamente en todo este

rango de condiciones, ajustando su ciclo de trabajo para mantener el seguimiento del punto

de máxima potencia del generador y adaptarse a los requisitos de carga de la batería.

## 4. Diseño del convertidor Boost

### 4.1. Análisis del funcionamiento del convertidor Boost

El convertidor DC-DC tipo Boost es una de las tipologías más utilizadas en electrónica de

potencia cuando se necesita elevar la tensión de una fuente de alimentación. Su principio de

funcionamiento se basa en el almacenamiento de energía de una inductancia y su posterior

transferencia a la carga mediante un proceso de conmutación controlado [6].

En el sistema planteado en este trabajo el convertidor Boost actúa como etapa intermedia

entre el generador fotovoltaico y la batería del vehículo eléctrico. Tal y como se ha descrito

en capítulos anteriores, el generador proporciona una tensión en el entorno de 220-250 V,

mientras que la batería requiere valores comprendidos entre 350 y 400 V. Esta diferencia de

niveles hace necesario el uso de un convertidor elevador.

El convertidor opera mediante la conmutación periódica de un interruptor electrónico,

generalmente un MOSFET. En este caso se considera una frecuencia de conmutación de 50

kHz y funcionamiento en modo de conducción continua (CCM), lo que implica que la corriente

que circula por la inductancia no llega a anularse durante el periodo de conmutación.

Para comprender su funcionamiento resulta conveniente analizar por separado los dos

estados principales del convertidor dentro de cada periodo de conmutación.

### 4.1.1. Intervalo de conducción (estado ON)

Cuando el interruptor principal se encuentra en conducción, el diodo queda polarizado en

inversa y no conduce. En esta situación la fuente de entrada alimenta directamente la

inductancia, que comienza a almacenar energía en forma de campo magnético.

La tensión en la inductancia durante este intervalo es igual a la tensión de entrada:

VL = Vin | (6)

Como consecuencia, la corriente por la inductancia aumenta de forma

aproximadamente lineal, según la expresión:

dIL
dt =
Vin L | (7)

Durante este intervalo la carga no recibe energía directamente del generador, sino que es

el condensador de salida el encargado de mantener la tensión en la carga.

### 4.1.2. Intervalo de corte (estado OFF)

Cuando el interruptor se abre, el diodo pasa a estar polarizado en directa y permite el

paso de corriente hacia la carga. En este estado la inductancia libera la energía previamente

almacenada, que se suma a la tensión de entrada.

La tensión en la inductancia, durante este estado de funcionamiento, viene dada por:

VL = Vin − Vout | (8)

Dado que la tensión de salida es superior a la de entrada, esta expresión resulta negativa,

lo que provoca una disminución de la corriente en la inductancia:

dIL
dt =
Vin − Vout L | (9)

En este intervalo, tanto el generador como la inductancia suministran energía a la carga.

### 4.1.3. Funcionamiento en régimen permanente

En condiciones de funcionamiento en régimen permanente, el convertidor opera de forma

periódica, de modo que la corriente por la inductancia al inicio y al final de cada periodo es la

misma. Esto implica que la variación media de la corriente en la inductancia es nula.

Con esta condición se puede plantear el balance de tensiones en la inductancia (Balance

voltio-segundos) a lo largo de un periodo de conmutación:

Vin ∙ D + (Vin − Vout) ∙ (1 − D) = 0 | (10)

A partir de esta expresión se obtiene la relación característica del convertidor Boost:

Vout =

Vin
1 − D

(11)

La ecuación muestra que la tensión de salida depende directamente del ciclo de trabajo

del interruptor, lo que permite regular la tensión de salida mediante el control de este [6].

### 4.1.4. Formas de onda características

Desde el punto de vista de las señales eléctricas, el funcionamiento del convertidor se

puede interpretar observando las formas de onda de sus principales variables.

La corriente por la inductancia presenta una forma aproximadamente triangular,

aumentando durante el intervalo ON y disminuyendo durante el intervalo OFF. En modo de

conducción continua los mínimos de corriente no llegan a cero.

La señal de control del interruptor es una señal PWM (Pulse Width Modulation), cuyo ciclo

de trabajo determina el tiempo relativo en el que el interruptor permanece en conducción.

La tensión en los interruptores de conmutación (principal y diodo) varía entre valores

cercanos a cero cuando están en conducción y valores próximos a la tensión de salida cuando

se encuentra en bloqueo, como se muestra en la Figura. 5.

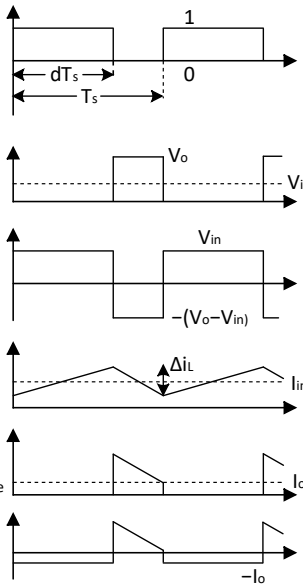
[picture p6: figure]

Figura 5. Formas de onda del convertidor Boost [21]

Este comportamiento permite identificar de forma clara los intervalos de almacenamiento

y transferencia de energía, lo cual resulta especialmente útil para el posterior cálculo del

rizado de corriente y tensión.

### 4.1.5. Aplicación al sistema propuesto

En el sistema elegido la tensión de entrada al convertidor que proporciona el generador

fotovoltaico se sitúa entre 220 y 250 V, mientras que la tensión de salida requerida por la

batería del vehículo eléctrico se encuentra entre 350 y 400 V.

A partir de la ecuación (11), se puede estimar que el convertidor debe operar con un ciclo

de trabajo comprendido aproximadamente entre 0,35 y 0,45. Este rango resulta adecuado

desde el punto de vista del diseño ya que permite un funcionamiento estable sin llevar los

componentes a condiciones extremas. Por tanto, el control del ciclo de trabajo se convierte

en el elemento clave para regular la tensión de salida del convertidor.

### 4.2. Cálculo de ciclo de trabajo

Una vez se ha analizado el funcionamiento del convertidor Boost, el siguiente paso es

determinar el ciclo de trabajo necesario para cumplir requisitos de tensión del sistema. Como

se ha visto anteriormente, en condiciones ideales y en régimen estacionario la relación entre

la tensión de salida y la tensión de entrada viene dada por la ecuación (11):

Vout =

Vin
1 − D

(11)

A partir de esta expresión, el ciclo de trabajo puede obtenerse despejando D:

D = 1 −

Vin

Vout

(12)

En este trabajo se considera una tensión de salida nominal de 380 V, valor intermedio

dentro del rango habitual de tensiones de baterías contemplado para el sistema. La tensión

de entrada del generador fotovoltaico puede variar aproximadamente entre 220 V y 250 V,

dependiendo de las condiciones de operación.

Con estos valores se analiza el ciclo de trabajo en distintos casos representativos.

### 4.2.1. Cálculo para tensión de entrada mínima

En la situación más desfavorable desde el punto de vista del convertidor, la tensión de

entrada toma su valor más bajo, Vin = 220 V. Sustituyendo en la ecuación (12):

D = 1 −

220
380 | (13)
D = 0,421 | (14)

Para una tensión de entrada de 220 V y una tensión de salida de 380 V, el convertidor

debe trabajar con un ciclo de trabajo aproximado de 0,42.

### 4.2.2. Cálculo para tensión de entrada máxima

En condiciones más favorables, cuando la tensión del generador aumenta hasta Vin = 250

V, el ciclo de trabajo necesario disminuye. Sustituyendo de nuevo en la ecuación (12):

D = 1 −

250
380 | (15)
D = 0,342 | (16)

En este caso el convertidor debe operar con un ciclo de trabajo aproximado de 0,34.

### 4.2.3. Rango de funcionamiento de ciclo de trabajo

A partir de los resultados anteriores se obtiene que el convertidor deberá trabajar en un

rango aproximado de:

0,34 ≤ D ≤ 0,42 | (17)

Este intervalo resulta adecuado para el funcionamiento del convertidor evitando valores

excesivamente altos de ciclo de trabajo, que podrían dificultar el control del sistema y

aumentar los esfuerzos eléctricos sobre los componentes.

Además, este rango confirma que la tipología Boost es apropiada para la aplicación

planteada y permite alcanzar la tensión de salida requerida sin necesidad de operar cerca de

sus límites teóricos.

Para resumir los valores obtenidos se presenta la siguiente tabla:

Vin (V) | Vout (V) | D
220 | 380 | 0,421
235 | 380 | 0,382
250 | 380 | 0,342

Tabla 1. Valores de Vin, Vout y su respectivo ciclo de trabajo

El ciclo de trabajo disminuye a medida que aumenta la tensión de entrada para mantener

la tensión de salida constante.

### 4.3. Dimensionado de la inductancia

La inductancia es uno de los elementos más importantes dentro del convertidor Boost. Se

encarga de almacenar energía cuando el interruptor principal está en conducción y liberarla

posteriormente hacia la carga. Por este motivo su dimensionado tiene una influencia directa

tanto en el funcionamiento del convertidor como en la calidad de la señal de corriente.

Además, al estar situado en la entrada del convertidor, el rizado de corriente de la inductancia

afecta directamente a la corriente extraída del generador fotovoltaico.

Un valor de inductancia bajo puede provocar un rizado elevado en la corriente, que

aumenta las pérdidas y el estrés sobre los componentes. Por el contrario, un valor alto mejora

el rizado, pero implica un mayor tamaño físico del dispositivo magnético y, por tanto, un mayor

coste. Por todo ello, es necesario encontrar un equilibrio adecuado entre estos factores [15].

### 4.3.1. Criterio de diseño adoptado

Para dimensionar de forma adecuada la inductancia, uno de los parámetros clave es el

rizado de corriente. En convertidores Boost es habitual fijar este rizado como un porcentaje

de la corriente media por la inductancia.

En la práctica este valor suele situarse entre el 20% y 40%, dependiendo de la aplicación.

En este trabajo se ha optado por un valor intermedio del 30% que permite mantener un rizado

moderado sin aumentar en exceso el tamaño de la bobina.

### 4.3.2. Estimación de la corriente de la Inductancia

La corriente media que circula por la inductancia puede aproximarse a partir de la potencia

del sistema. Suponiendo un comportamiento ideal, la potencia de entrada es

aproximadamente igual a la de salida:

P = Vin ∙ Iin | (18)

Despejando la corriente:

Iin =

P

Vin

(19)

Para el sistema considerado, con una potencia aproximada de 2,4 kW, y tomando el caso

más desfavorable en el que la tensión de entrada es mínima (Vin = 220 V):

Iin =

2400
220 | (20)
Iin ≈ 10,9A | (21)

Este valor se puede considerar una buena aproximación de la corriente media por la

inductancia.

### 4.3.3. Cálculo del rizado de corriente

Una vez se ha establecido un valor de la corriente media de entrada, se calcula el rizado

pico a pico de corriente como un porcentaje de este:

∆IL = 0,3 ∙ Iin | (22)
∆IL = 0,3 ∙ 10,9 ≈ 3,27A | (23)

Este valor representa la variación pico a pico de la corriente de la inductancia.

### 4.3.4. Obtención del valor de la inductancia

A partir del análisis del convertidor Boost en modo de conducción continua, el rizado de

corriente viene dado por la siguiente expresión [15]:

∆IL =

Vin ∙ D
L ∙ f

(24)

Despejando el valor de la inductancia:

L =

Vin ∙ D
∆IL
- f

(25)

Para el cálculo se consideran los valores correspondientes al caso más desfavorable:

- Vin = 220V
- D = 0,42
- ΔIL = 3,27 A
- f = 50 kHz

Sustituyendo:

L =

220 ∙ 0,42
3,27 ∙ 50000 | (26)
L ≈ 565μH | (27)

### 4.3.5. Selección del valor final

El valor obtenido corresponde al mínimo necesario para cumplir el criterio de rizado

establecido. Sin embargo, en un diseño real es habitual seleccionar un valor ligeramente

superior para asegurar el funcionamiento correcto en condiciones no ideales, como

variaciones de temperatura, tolerancias de los componentes o pérdidas en el sistema.

Por este motivo se selecciona un valor comercial próximo: L = 600 µH

Este valor permite mantener el convertidor en modo de conducción continua y limitar el

rizado de corriente dentro de un rango adecuado, garantizando un funcionamiento estable del

sistema. Aunque el cálculo realizado se basa en condiciones ideales, proporciona una

estimación suficientemente precisa para el dimensionado inicial del convertidor. En una fase

posterior este valor podría ajustarse teniendo en cuenta efectos no ideales o resultados

obtenidos mediante simulación.

### 4.4. Selección del interruptor y del diodo

Una vez definidos los parámetros principales del convertidor, como el ciclo de trabajo y el

valor de la inductancia, el siguiente paso es seleccionar los dispositivos de conmutación. En

este caso se trata del interruptor electrónico principal y el diodo de potencia.

La elección de estos componentes es especialmente importante porque van a estar

sometidos a tensiones y corrientes relativamente elevadas, y además su comportamiento

influye directamente en el rendimiento del convertidor. No solo hay que cumplir con los valores

eléctricos, sino también tener en cuenta aspectos como las pérdidas o la frecuencia de

conmutación [15].

### 4.4.1. Selección del interruptor principal (MOSFET)

En este tipo de aplicaciones el dispositivo más habitual para realizar la conmutación es el

MOSFET. Esto se debe principalmente a su rapidez de conmutación y a que su control es

relativamente sencillo.

- Tensión que tiene que soportar en bloqueo

En un convertidor Boost, cuando el interruptor está abierto, debe soportar prácticamente

toda la tensión de salida. Por tanto, se puede considerar:

VDS,max ≈ Vout | (28)

Teniendo en cuenta que en este trabajo la tensión de salida puede alcanzar valores

cercanos a 400 V, es recomendable añadir un margen de seguridad para evitar problemas

en condiciones reales de funcionamiento.

Aplicando un factor de seguridad del orden de 1,3:

VDS,max ≥ 1,3 ∙ 400 ≈ 520V | (29)

Una elección razonable sería un MOSFET de 600 V, que es un valor bastante habitual en

este tipo de aplicaciones.

- Corriente que tiene que soportar en conducción

La corriente que circula por el MOSFET coincide con la de la inductancia durante el

intervalo de conducción. Hay que considerar tanto la corriente media como el rizado.

La corriente máxima puede estimarse como:

Imax = IL +

∆IL
2

(30)

Sustituyendo los valores calculados anteriormente:

Imax = 10,9 +

3,27
2
≈ 12,5A | (31)

En la práctica es recomendable no ajustar demasiado este valor y dejar cierto margen,

por lo que sería razonable seleccionar un dispositivo con una corriente nominal de al menos

15 A o incluso 20 A.

- Otros aspectos por considerar

Hay otros parámetros que también influyen en el comportamiento del MOSFET:

- La resistencia en condición RDS(on), que afecta a las pérdidas
- Los tiempos de conmutación
- La capacidad de disipación térmica

En general un valor bajo de RDS(on) es deseable, reduce las pérdidas por conducción,

aunque esto suele implicar un mayor coste del dispositivo [15]

Desde el punto de vista del funcionamiento, el MOSFET conduce durante el intervalo ON

del convertidor permitiendo el paso de corriente a través de la inductancia. En este estado las

pérdidas están principalmente asociadas a la resistencia en conducción del dispositivo.

Por el contrario, durante el intervalo en OFF, el MOSFET permanece en corte y debe

soportar la tensión de salida del convertidor. En esta situación las pérdidas están relacionadas

principalmente con los procesos de conmutación, especialmente en el instante de encendido

y apagado.

### 4.4.2. Selección del diodo

El diodo es el encargado de conducir la corriente hacia la carga cuando el interruptor

principal está en bloqueo. Aunque su funcionamiento es más sencillo que el MOSFET, su

selección también es importante, especialmente en aplicaciones con conmutación a alta

frecuencia.

- Tensión que tiene que soportar en bloqueo

Al igual que en el caso del MOSFET, el diodo debe soportar aproximadamente la tensión

de salida:

VDS,max ≈ Vout | (32)

Por tanto, se selecciona igualmente un diodo con una tensión nominal de 600 V,

manteniendo el mismo margen de seguridad.

- Corriente que tiene que soportar en conducción

La corriente que circula por el diodo se corresponde con la que atraviesa la inductancia

durante el intervalo de OFF y se puede tomar como referencia el mismo valor calculado

anteriormente.

De nuevo es recomendable seleccionar un dispositivo con cierto margen, por lo que una

corriente nominal 15-20 A resulta adecuada.

- Tipo de diodo

En este caso la frecuencia de conmutación es de 50 kHz, por lo que no es recomendable

utilizar diodos rectificadores convencionales, sus tiempos de recuperación pueden generar

pérdidas importantes.

Las opciones más habituales son:

- Diodos ultrarrápidos
- Diodos basados en SiC
- Diodo schottky

Para tensiones elevadas como las consideradas en este trabajo, los diodos SiC presentan

ventajas como menores pérdidas y mejor comportamiento en conmutación, aunque su coste

es mayor [16].

En cuanto al funcionamiento, el diodo conduce durante el intervalo OFF del convertidor,

permitiendo el paso de corriente hacia la carga. Durante el intervalo ON, el diodo se encuentra

bloqueado, soportando la tensión de salida.

### 4.4.3. Consideraciones finales

Los cálculos anteriores permiten estimar los valores mínimos necesarios, en un diseño

real siempre es recomendable seleccionar los componentes con cierto margen de seguridad.

Además, factores como la temperatura, las tolerancias de fabricación o las condiciones de

funcionamiento pueden afectar al comportamiento del convertidor.

Por todo ello, la selección realizada en este trabajo se puede considerar conservadora,

priorizando la fiabilidad del sistema. En una fase posterior sería posible optimizar el diseño

analizando en detalle las pérdidas y la eficiencia del convertidor.

### 4.5. Cálculo del condensador de salida

Es otro de los elementos fundamentales del convertidor Boost. Su función principal es

filtrar la tensión entregada a la carga y reducir el rizado de salida. Ayuda a que la tensión no

presente variaciones bruscas debidas al proceso de conmutación del convertidor.

Durante el funcionamiento del Boost, especialmente en el intervalo en el que el interruptor

está cerrado, la carga no recibe energía directamente a través del diodo, por lo que es el

condensador el que debe suministrar parte de la energía necesaria. Por este motivo su valor

debe seleccionarse de forma que el rizado de tensión se mantenga dentro de unos límites

aceptables [15].

### 4.5.1. Criterio de diseño adoptado

Para dimensionar el condensador de salida es necesario fijar previamente un criterio de

rizado de tensión admisible. En convertidores de este tipo, lo habitual es permitir un pequeño

rizado respecto al valor nominal de salida, normalmente del orden del 1% al 5%, dependiendo

del nivel de exigencia de la aplicación.

En este trabajo se adopta un criterio de diseño de limitar el rizado de pico a pico ∆Voutpp,

al 2% de la tensión de salida nominal, ya que se trata de un valor razonable para mantener

una salida suficientemente estable.

Tomando como tensión de salida de referencia:

Vout = 380V | (33)

El rizado máximo permitido será:

∆Voutpp = 0,02 ∙ Vout | (34)
∆Vout = 0,02 ∙ 380 = 7,6V | (35)

Por tanto, en el diseño se considerará un rizado de tensión máximo de 7,6 V.

### 4.5.2. Corriente de salida del sistema

Para calcular el valor del condensador, primero conviene estimar la corriente de salida. A

partir de la potencia de salida y de la tensión nominal de salida puede obtenerse una

aproximación de dicha corriente:

P = Vout ∙ Iout | (36)

Despejando:

Iout =

P

Vout

(37)

Sustituyendo los valores del sistema:

Iout =

2400
380 | (38)
Iout ≈ 6,32A | (39)

Este valor representa la corriente media que demanda la carga en condiciones nominales.

### 4.5.3. Expresión para el cálculo del condensador

En un convertidor Boost una forma habitual de estimar el condensador de salida consiste

en relacionar la corriente de salida, el ciclo de trabajo, la frecuencia de conmutación y el rizado

de tensión permitido. Bajo hipótesis ideales puede utilizarse la expresión [15]:

C =

Iout ∙ D f ∙ ∆Voutpp | (40)

Esta ecuación permite obtener un valor mínimo del condensador necesario para mantener

el rizado de tensión dentro del límite establecido.

Como en el diseño anterior, se toma el caso más desfavorable, es decir, aquel en el que

el ciclo de trabajo es mayor. En este caso se utiliza:

- Iout = 6,32 A
- D = 0,42
- f = 50 kHz
- ∆Voutpp = 7,6 V

Sustituyendo en la ecuación (40):

C =

6,32 ∙ 0,42 50000 ∙ 7,6 | (41)
C ≈ 6,99 μF | (42)

Por tanto, el valor mínimo obtenido para el condensador de salida es aproximadamente 7

µF.

### 4.5.4. Selección del valor final

El valor calculado proporciona una referencia inicial, pero en la práctica no suele elegirse

exactamente el valor mínimo teórico. Lo habitual es seleccionar un condensador de mayor

capacidad para compensar efectos no ideales: tolerancias del componente, envejecimiento y

posibles variaciones de carga.

En aplicaciones de potencia como esta, el comportamiento real del condensador no

depende únicamente de su capacidad nominal. También influyen parámetros como la

resistencia serie equivalente (ESR), la corriente de rizado admisible y el comportamiento

térmico.

Es razonable seleccionar un valor superior al mínimo calculado. En este caso una opción

adecuada podría ser: C = 10 µF. Este valor proporciona cierto margen respecto al cálculo

teórico y permite reducir el rizado de tensión de salida en condiciones reales de

funcionamiento.

### 4.5.5. Consideraciones prácticas

En un convertidor real el uso de un único condensador no siempre es la mejor solución.

En muchos diseños prácticos se emplean varios condensadores en paralelo combinando, por

ejemplo:

- Condensadores electrolíticos, por su mayor capacidad.
- Condensadores cerámicos o de film, por su mejor comportamiento a alta frecuencia y

menor ESR.

Esta combinación permite mejorar tanto la capacidad total como la respuesta frente al

rizado de alta frecuencia.

También conviene recordar que el condensador de salida va a estar sometido a una

tensión elevada, por lo que su tensión nominal debe ser superior a la tensión máxima de

salida del convertidor. En este caso al trabajar en torno a 380-400 V será necesario

seleccionar un componente con margen suficiente, por ejemplo, de 450 V o superior,

dependiendo de la disponibilidad comercial.

El valor obtenido en este apartado debe entenderse como un punto de partida para el

diseño del convertidor. En una fase posterior este cálculo puede completarse mediante

simulación, observando el rizado real de la tensión de salida y ajustando el valor del

condensador si fuese necesario. De esta forma el condensador no solo se selecciona a partir

de una expresión teórica, sino también teniendo en cuenta el comportamiento global del

sistema.

### 4.6. Estimación de pérdidas y eficiencia

Una vez dimensionados los principales componentes del convertidor, resulta interesante

realizar una estimación de las pérdidas del sistema y de su eficiencia. Aunque en los

apartados anteriores se ha trabajado bajo hipótesis ideales, en un convertidor real existen

diferentes mecanismos de pérdidas que afectan al rendimiento global.

El análisis que se presenta a continuación no pretende ser muy exhaustivo, sino

proporcionar una estimación razonable que permita evaluar el comportamiento del sistema,

siguiendo modelos habituales en el estudio de convertidores DC-DC [6][15].

### 4.6.1. Principales fuentes de pérdidas

En un convertidor Boost las pérdidas más importantes suelen estar asociadas a los

siguientes elementos:

- Pérdidas en el MOSFET
- Pérdidas en el diodo
- Pérdidas en la inductancia
- Pérdidas en el condensador (generalmente menores)

### 4.6.2. Pérdidas en el MOSFET

Las pérdidas en el MOSFET se pueden dividir en dos tipos principales:

- Pérdidas de conducción

Se produce cuando el MOSFET está en estado ON y depende de su resistencia interna

RDS(on):

Pcond = I

2
- RDS(on)
(43)

Tomando como referencia una corriente media de aproximadamente 10,9 A y suponiendo

un valor típico de RDS(on) = 0,1 Ω:

Pcond = (10,9)

2
- 0,1 ≈ 11,9 W | (44)
- Pérdidas de conmutación

Estas pérdidas aparecen durante los transitorios de encendido y apagado del MOSFET.

Una forma sencilla de estimarlas es:

Psw =

1
2
- V ∙ I ∙ (ton + toff) ∙ f | (45)

Suponiendo:

- V = 380 V
- I = 10,9 A
- ton + toff = 100 ns
- f = 50 kHz
Psw ≈ 10,4W | (46)

Las pérdidas totales del MOSFET tienen un valor de 22 W

### 4.6.3. Pérdidas en el diodo

El diodo presenta principalmente pérdidas por conducción, que dependen de su caída de

tensión directa:

PD = Vf ∙ I | (47)

Suponiendo una caída típica de Vf = 1 V:

PD = 1 ∙ 6,3 ≈ 6,3W | (48)

### 4.6.4. Pérdidas en la inductancia

Las pérdidas en la inductancia se deben principalmente a la resistencia del bobinado, es decir,

a las pérdidas en el cobre:

PL = I

2
- RL | (49)

Suponiendo una resistencia aproximada de RL = 0,05 Ω:

PL = (10,9)

2
- 0,05 ≈ 6W | (50)

### 4.6.5. Estimación de pérdidas totales

Sumando las principales contribuciones:

- MOSFET = 22 W
- Diodo = 6,3 W
- Inductancia = 6 W

Se obtienen unas pérdidas totales de 34 W

### 4.6.6. Cálculo de la eficiencia

Se considera la potencia correspondiente a la potencia nominal del generador fotovoltaico

definido en el apartado 3.1. La eficiencia del convertidor se puede estimar como:

η =

Pout

Pout + Pperdidas

(51)

Sustituyendo:

η =

2400
2400 + 34 | (52)
η ≈ 98,6 % | (53)

El valor obtenido corresponde a una estimación idealizada, no se han tenido en cuenta

todos los efectos no ideales del sistema. En la práctica la eficiencia real será ligeramente

inferior debido a pérdidas adicionales como las asociadas al condensador, conexiones,

efectos térmicos o comportamiento no ideal de los dispositivos.

El resultado obtenido permite concluir que el convertidor diseñado puede alcanzar una

eficiencia elevada, lo cual es coherente con este tipo de tipologías en aplicaciones de potencia

media [6][15].

## 5. Diseño de control

Una vez definido el convertidor y calculados sus principales componentes, el siguiente

paso es plantear cómo se va a controlar el sistema en la práctica. En este tipo de aplicaciones

el control es una parte importante, ya que el comportamiento del generador fotovoltaico no es

constante y depende en todo momento de la irradiancia y de la temperatura [19].

Esto hace que el convertidor no pueda funcionar con un valor fijo de ciclo de trabajo, sino

que es necesario ajustarlo continuamente para adaptarse a las condiciones de

funcionamiento. Además, no solo interesa extraer la máxima potencia posible del panel, sino

también hacerlo de forma compatible con el proceso de carga de la batería.

Por este motivo en el sistema propuesto se plantean dos objetivos principales. Por un

lado, trabajar en el punto de máxima potencia del generador fotovoltaico mediante un

algoritmo MPPT y, por otro lado, tener en cuenta las condiciones de carga de la batería, que

en este tipo de aplicaciones suele seguir una estrategia de corriente constante-tensión

constante [12][13].

No se busca desarrollar un sistema de control complejo, sino más bien una solución que

funcione bien y poder desarrollar un prototipo con el que verificar su funcionamiento. En este

sentido se ha pensado en una implementación basada en un microcontrolador ESP32S, que

permite realizar medidas, cálculos y generación de señales PWM de forma bastante directa.

### 5.1. Estructura general del control

Si se intenta ver el sistema de forma global, el control se puede entender como un proceso

que se repite continuamente: se miden varias variables, se toman decisiones y se actúa sobre

el convertidor.

En primer lugar, es necesario medir la tensión y la corriente del generador fotovoltaico.

Estas dos magnitudes son fundamentales pues a partir de ellas se puede calcular la potencia

instantánea. Esta potencia es la referencia principal que utiliza el algoritmo MPPT para decidir

cómo debe actuar el sistema [11].

Una vez se dispone de estas medidas, el siguiente paso es procesarlas. En cada instante,

el sistema calcula la potencia y la compara con la obtenida en el ciclo anterior. Con esta

información el algoritmo decide si el punto de operación actual es mejor o peor que el anterior

y en función de eso ajusta el ciclo de trabajo al convertidor.

La forma en la que se actúa sobre el sistema es mediante la señal PWM que controla el

interruptor del convertidor Boost. Modificando el ciclo de trabajo de esta señal se consigue desplazar el punto de funcionamiento del generador sobre su curva característica,

acercándolo al punto de máxima potencia [6][8].

En la práctica todo este proceso se ejecuta de forma repetitiva en el microcontrolador, es

decir, el sistema está continuamente midiendo, calculando y ajustando el ciclo de trabajo, de

manera que se adapta en tiempo real a los cambios de irradiancia o de temperatura.

Desde el punto de vista de implementación, este tipo de control se puede llevar a cabo

con un ESP32S. Este microcontrolador permite leer señales analógicas mediante sus

entradas, realizar cálculos básicos y generar señales PWM sin necesidad de hardware

adicional complejo. Resulta una opción adecuada para un prototipo como el planteado en

este trabajo.

La estructura de control que se plantea es más que suficiente para cumplir los objetivos

del sistema. En los siguientes apartados se detallará el funcionamiento del algoritmo MPPT

utilizado y cómo se integra con el proceso de carga de la batería.

### 5.2. Implementación del algoritmo MPPT (P&O)

El control del sistema tiene como objetivo principal que el generador fotovoltaico trabaje

en un punto cercano al de máxima potencia en cada momento. El problema es que ese punto

no es fijo, sino que cambia continuamente con la irradiancia y la temperatura, por lo que no

basta con ajustar el sistema una vez y dejarlo funcionando.

Es necesario utilizar un algoritmo que vaya corrigiendo el punto de operación de forma

continua. En este trabajo se ha optado por el método de perturbación y observación (P&O),

es uno de los más utilizados en este tipo de aplicaciones y permite obtener un funcionamiento

correcto sin necesidad de complicar el sistema de control [11].

### 5.2.1. Fundamento del método P&O

En lugar de calcular directamente donde está el punto de máxima potencia, lo que hace

es ir ajustando poco a poco el punto de funcionamiento y observar qué ocurre con la potencia.

En cada ciclo el sistema realiza un pequeño cambio en el ciclo de trabajo del convertidor

y mide la potencia resultante. A partir de ahí, compara ese valor con el anterior. Si el cambio

ha hecho que la potencia aumente, se entiende que se va en la dirección correcta y se

continúa en ese mismo sentido. Si por el contrario la potencia disminuye, se asume que el

ajuste no ha sido adecuado y se cambia la dirección.

Este proceso se repite de forma continua, de manera que el punto de funcionamiento del

sistema se va desplazando progresivamente hasta situarse en las proximidades del punto de

máxima potencia.

### 5.2.2. Cómo actúa sobre el sistema

El algoritmo no actúa directamente sobre el panel fotovoltaico, sino sobre el convertidor

Boost.

El parámetro que se modifica es el ciclo de trabajo de la señal PWM que controla el

interruptor. Al variar este ciclo de trabajo, cambia el punto en el que el panel está trabajando

y modifica la relación entre tensión y corriente que presenta el generador.

El convertidor actúa como elemento de adaptación entre el panel y la carga, permitiendo

desplazar el punto de operación sobre la curva característica del generador sin necesidad de

modificar físicamente el sistema [6][8].

### 5.2.3. Funcionamiento durante la operación

El algoritmo se ejecuta de forma repetitiva mientras el sistema está en funcionamiento.

En cada iteración se siguen siempre los mismos pasos, aunque en la práctica todo ocurre a

gran velocidad.

En primer lugar, se mide la tensión y la corriente del generador fotovoltaico. Con estos

valores se calcula la potencia en ese instante. A continuación, dicha potencia se compara con

la obtenida en la iteración anterior, lo que permite evaluar si el último ajuste realizado ha sido

adecuado.

En función de esa comparación el sistema decide si continúa modificando el ciclo de

trabajo en la misma dirección o si invierte el sentido del cambio. Esta decisión se traduce en

una pequeña variación del ciclo de trabajo, que se aplica mediante la señal PWM que controla

el convertidor.

Este proceso se repite continuamente, lo que permite que el sistema se adapte de forma

progresiva a las condiciones de funcionamiento sin necesidad de una intervención externa.

Para facilitar la comprensión del funcionamiento del algoritmo, en la Figura 6 se muestra

un diagrama de flujo simplificado del método P&O implementado en el sistema.

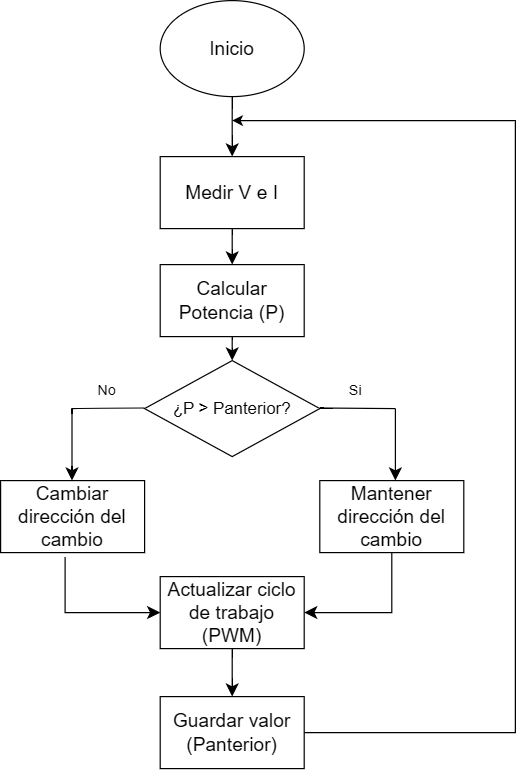
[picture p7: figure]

Figura 6. Diagrama de flujo del algoritmo MPPT tipo P&O

### 5.2.4. Comportamiento real del algoritmo

En condiciones reales el comportamiento del algoritmo no es perfecto, y eso es algo que

conviene tener en cuenta. Por ejemplo, el sistema no se queda exactamente en el punto de

máxima potencia, sino que se mueve ligeramente alrededor de él. Esto ocurre porque el

propio algoritmo está introduciendo continuamente pequeñas variaciones para comprobar

hacia dónde debe ajustarse.

Cuando se producen cambios rápidos en las condiciones ambientales, como variaciones

bruscas de irradiancia, el sistema no responde de forma instantánea. Al basarse en

comparaciones entre ciclos consecutivos, necesita varias iteraciones para ajustarse de nuevo

al punto de funcionamiento.

A pesar de estas limitaciones, este comportamiento es característico de este tipo de

algoritmos y, en la mayoría de las aplicaciones, no supone un problema significativo en el

rendimiento global del sistema [11].

### 5.2.5. Implementación práctica

A la hora de llevar este algoritmo a la práctica no es necesario un hardware especialmente

complejo. Un microcontrolador como el ESP32S es suficiente para implementar esta lógica

de control.

El sistema debe encargarse de adquirir las señales de tensión y corriente mediante

entradas analógicas, calcular la potencia en cada ciclo y actualizar el ciclo de trabajo del

convertidor en función del resultado obtenido. Es necesario almacenar ciertos valores entre

iteraciones como la potencia anterior y esta información es la que permite tomar decisiones

en cada paso.

El comportamiento del sistema también depende de cómo se realicen los ajustes sobre el

ciclo de trabajo. Si las variaciones son demasiado grandes, el sistema puede alejarse del

punto de máxima potencia con facilidad. En cambio, si los cambios son muy pequeños, la

adaptación frente a cambios en las condiciones de funcionamiento puede resultar más lenta.

Es importante que estos ajustes se realicen de forma progresiva, de manera que el sistema

mantenga un funcionamiento estable sin perder capacidad de respuesta.

### 5.3. Integración con la estrategia de carga CC-CV

El sistema de control se ha planteado con el objetivo de maximizar la potencia extraída

del generador fotovoltaico mediante el algoritmo MPPT. Sin embargo, en una aplicación real

como la carga de un vehículo eléctrico, no siempre es posible trabajar únicamente en ese

modo.

La batería no puede aceptar cualquier valor de tensión o corriente en cualquier momento.

Su proceso de carga sigue unas condiciones determinadas que deben respetarse para

garantizar su funcionamiento correcto y evitar posibles daños. Además del seguimiento del

punto de máxima potencia es necesario tener en cuenta la estrategia de carga de batería.

En este tipo de aplicaciones es habitual utilizar un perfil de carga de tipo corriente-tensión

constante (CC-CV), ampliamente empleado en baterías de ion-litio [12][13].

### 5.3.1. Funcionamiento conjunto del sistema

Durante el funcionamiento del sistema el control debe adaptarse tanto al comportamiento

del generador fotovoltaico como al estado de la batería. Esto hace que no exista un único

modo de funcionamiento, sino que el sistema vaya cambiando según las condiciones.

En una primera etapa, cuando la batería se encuentra descargada o en un nivel de carga

intermedio puede aceptar sin problema la energía suministrada por el generador. En esta

situación el sistema trabaja siguiendo el algoritmo MPPT, tratando de extraer la máxima

potencia disponible en cada instante.

A medida que la batería se va cargando, su tensión aumenta progresivamente. Cuando

se alcanza cierto nivel, ya no es conveniente seguir aumentando la potencia de carga sin control. El sistema debe limitar la tensión o la corriente dejando de priorizar el seguimiento

del punto de máxima potencia.

### 5.3.2. Adaptación del control

El paso entre el funcionamiento en modo MPPT y el control tipo CC-CV no se produce de

forma arbitraria, sino que depende principalmente de la tensión de la batería.

Mientras la batería se mantiene por debajo de su tensión máxima, el sistema puede operar

en modo MPPT sin restricciones. Sin embargo, cuando se alcanza el valor límite, el control

debe cambiar su comportamiento y comenzar a regular la salida del convertidor.

Esto implica que, en determinadas condiciones, el generador fotovoltaico no trabajará

exactamente en su punto de máxima potencia, ya que la prioridad pasa a ser el cumplimiento

de las condiciones de carga de batería. Es necesario equilibrar la eficiencia energética con la

seguridad del almacenamiento.

### 5.3.3. Consideraciones teóricas

En este trabajo la estrategia CC-CV se tiene en cuenta únicamente a nivel teórico, con el

objetivo de contextualizar el funcionamiento del sistema dentro de una aplicación real.

No se aborda el diseño detallado del control de carga de batería; esto implicaría añadir

un nivel adicional de complejidad que queda fuera del alcance principal del proyecto. Se

considera cómo esta estrategia condiciona el funcionamiento del convertidor y del algoritmo

MPPT.

Se asume que el sistema operará en modo MPPT siempre que las condiciones de la

batería lo permitan, y que en caso contrario sería necesario limitar la tensión o la corriente.

La consideración de la estrategia de carga CC-CV permite situar el sistema propuesto

dentro de un contexto de aplicación real, sin necesidad de desarrollar completamente el

control asociado a la batería permitiendo centrar el trabajo en el diseño del convertidor DC-

DC y del algoritmo MPPT, manteniendo al mismo tiempo una visión global del sistema en que

se integra [12][13][22].

## 6. Simulación del Sistema

Lo que interesa comprobar en este punto es la respuesta del convertidor cuando se lleva

a un modelo Simulink.

Primero se analiza el comportamiento del convertidor en lazo abierto utilizando un ciclo

de trabajo fijo. Se comprueba que las tensiones y corrientes son coherentes con lo calculado

anteriormente y una vez hecho esto se introduce el control MPPT que permite que el sistema

deje de trabajar en un punto fijo y empiece a ajustarse de forma automática.

Por último, se plantea una situación en la que cambian las condiciones de funcionamiento,

en concreto la irradiancia, y así se puede verificar que el sistema es capaz de reaccionar y

adaptarse, que es la finalidad de este tipo de control.

### 6.1. Modelo del convertidor en Simulink

Con el objetivo de comprobar el comportamiento del convertidor diseñado, se ha

desarrollado un modelo de simulación en el entorno de MATLAB/Simulink, utilizando las

librerías de Simscape y Simscape Electrical. Este tipo de herramientas permiten trabajar

directamente con componentes eléctricos, lo que facilita representar el funcionamiento del

circuito sin tener que recurrir a simplificaciones excesivas.

Frente al modelo puramente teórico, este enfoque permite observar directamente

magnitudes como tensiones y corrientes en distintos puntos del circuito, lo que resulta útil

para comprobar si el comportamiento obtenido coincide con lo esperado a partir del diseño

realizado en los capítulos anteriores.

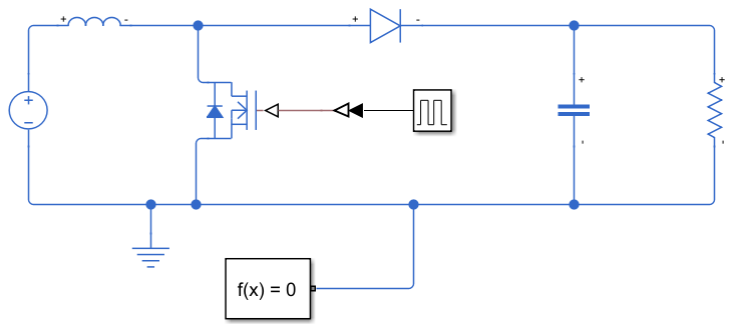
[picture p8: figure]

Figura 7. Esquema del convertidor implementado

### 6.1.1. Implementación del convertidor Boost

El modelo desarrollado sigue la estructura básica del convertidor Boost analizado

previamente. En la entrada se ha utilizado una fuente de tensión continua de 220 V que

representa de forma simplificada el generador fotovoltaico en condiciones de operación.

A la entrada del circuito, se sitúa la inductancia que es el elemento encargado de

almacenar energía durante el funcionamiento del convertidor.

Desde el nodo de salida de la inductancia el circuito se divide en dos caminos. Por un

lado, se encuentra el interruptor electrónico (MOSFET) que permite controlar el proceso de

conmutación y, por otro lado, se sitúa el diodo que conduce hacia la salida cuando el

interruptor se encuentra abierto.

El funcionamiento del modelo es el mismo que se ha descrito en el análisis teórico.

Cuando el MOSFET está en conducción, la inductancia almacena energía y el diodo

permanece bloqueado. Cuando el interruptor se abre, la inductancia libera la energía

almacenada y esta se transfiere hacia la salida a través del diodo.

En la etapa de salida se ha incluido un condensador en paralelo con una resistencia. El

condensador permite reducir el rizado de la tensión, mientras que la resistencia representa

de forma simplificada la carga del sistema.

El control del interruptor se realiza mediante una señal PWM generada en Simulink, con

una frecuencia de 50 kHz y un ciclo de trabajo constante de 0,421. Este valor se corresponde

con el caso más desfavorable obtenido en el diseño, lo que permite analizar el

comportamiento del convertidor en condiciones exigentes.

La simulación se ha planteado en lazo abierto, sin ningún tipo de control adicional. Así se

puede observar el comportamiento propio del convertidor sin la influencia del algoritmo MPPT

y comprobar el correcto diseño de los dispositivos del convertidor.

### 6.2. Simulación del convertidor en lazo abierto

El convertidor opera con un ciclo de trabajo constante de 0,421, correspondiente al caso

más desfavorable considerado en el dimensionado para una tensión de entrada de 220 V. Se

puede evaluar el comportamiento del sistema en condiciones exigentes.

### 6.2.1. Tensión de salida

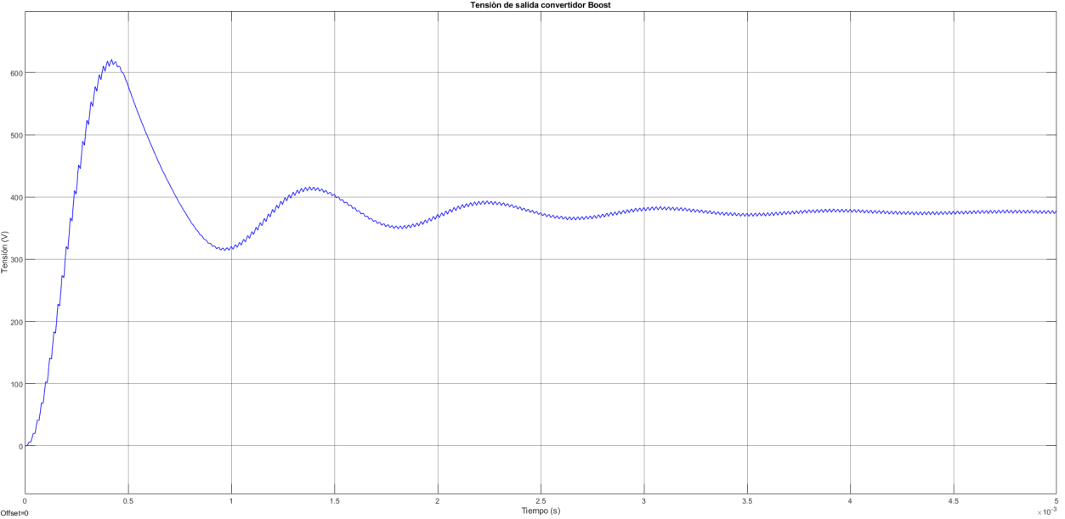
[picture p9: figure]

Figura 8. Tensión de salida del convertidor

Durante el arranque del sistema la tensión aumenta rápidamente desde cero hasta

alcanzar un valor máximo superior al nominal, observándose un sobreimpulso que alcanza

aproximadamente los 620 V. Este comportamiento es habitual en convertidores de este tipo

y se debe principalmente al proceso de carga inicial del condensador de salida.

Tras este primer transitorio, la tensión desciende y comienza a oscilar alrededor del

valor de régimen permanente, presentando una respuesta amortiguada. Finalmente, el

sistema se estabiliza en un valor próximo a 378 V, muy cercano al valor de diseño de 380 V.

Esta pequeña diferencia se puede atribuir a los efectos no ideales del modelo y a la

propia dinámica del sistema. En cualquier caso, confirma que el convertidor cumple con el

objetivo de elevar la tensión hasta el nivel requerido.

Una vez alcanzado el régimen estacionario se observa un ligero rizado en la tensión de

salida. Este rizado está asociado al proceso de conmutación del convertidor y a la carga y

descarga del condensador, tal y como se había considerado en el capítulo 4.

### 6.2.2. Corriente de la inductancia

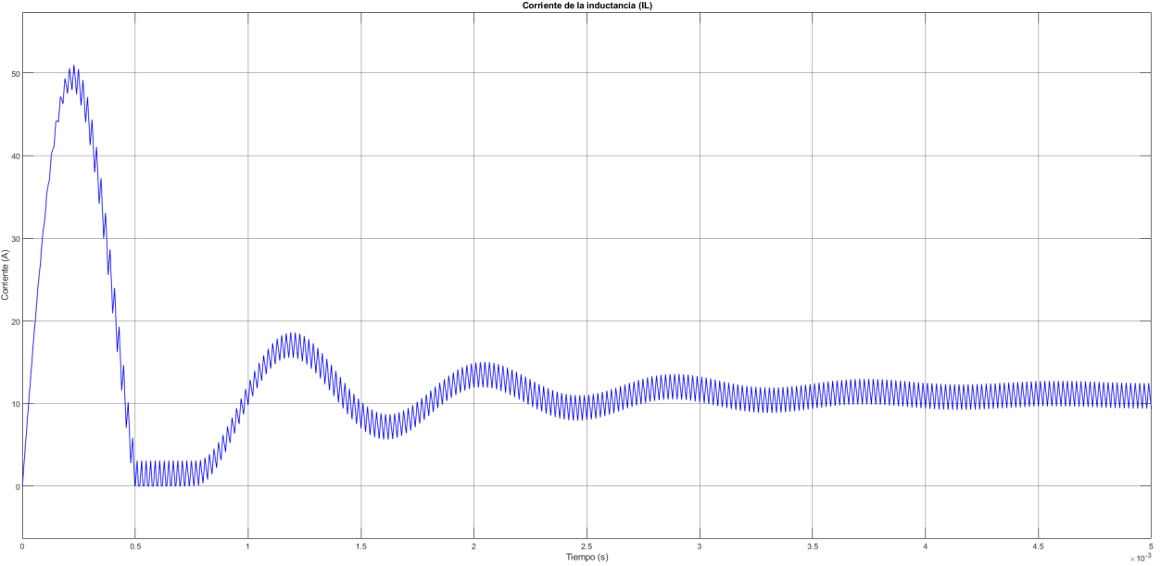
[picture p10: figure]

Figura 9. Corriente que circula por la inductancia

Durante el arranque la corriente de la inductancia presenta un pico transitorio antes

de alcanzar el régimen permanente. Este comportamiento está relacionado con el

funcionamiento en lazo abierto del convertidor, ya que el ciclo de trabajo se aplica

directamente desde el instante inicial y no existe ninguna estrategia de arranque suave ni

limitación de corriente.

Además, el condensador de salida parte inicialmente descargado, por lo que durante

los primeros instantes se produce una demanda elevada de energía hasta que se establece

el régimen de funcionamiento. Una vez superado el transitorio, la corriente se estabiliza en

torno a un valor medio de aproximadamente 11 a 12 A, lo cual resulta coherente con la

estimación en el diseño teórico del sistema.

En régimen permanente se aprecia claramente el rizado de la corriente de la

inductancia, con una forma aproximadamente triangular. Este comportamiento es

característico del modo de conducción continua (CCM) y confirma que el convertidor está

operando en las condiciones previstas.

El valor del rizado observado se encuentra dentro de un rango razonable respecto al valor

medio, lo que indica que el dimensionado de la inductancia es adecuado y cumple con el

criterio del diseño adoptado.

### 6.2.3. Análisis de los resultados

A partir de los resultados obtenidos se puede concluir que el comportamiento del

convertidor en simulación es coherente con el análisis teórico realizado.

La tensión de salida alcanza el valor esperado, validando el cálculo del ciclo de trabajo y

la corriente de la inductancia presenta un valor próximo al obtenido durante el dimensionado.

Para comprobar con mayor precisión el rizado de corriente se ha ampliado la señal de la

inductancia una vez alcanzado el régimen permanente. Mediante los cursores del Scope se

obtiene un valor máximo de 12,417 A y un valor mínimo de 9,467 A.

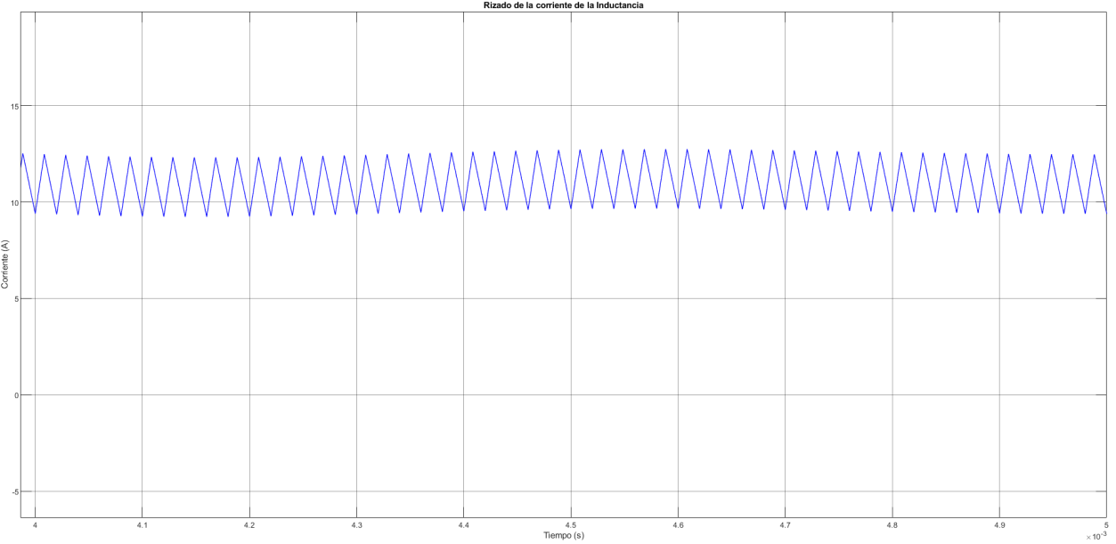
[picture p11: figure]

Figura 10. Medida del rizado de corriente de la inductancia en régimen permanente

Por tanto, el rizado pico a pico de corriente es:

∆IL = 12,417 − 9,467 = 2,950 A | (54)

El valor obtenido es próximo al rizado teórico de 3,27 A calculado en el apartado 4.3.3,

por lo que el comportamiento de la corriente resulta coherente con el dimensionado de la

inductancia.

También se ha realizado una ampliación de la tensión de salida en régimen permanente

para comprobar el rizado asociado a la carga y descarga del condensador. En este caso se

obtiene un valor máximo de 378,075 y un valor mínimo de 373,226 V.

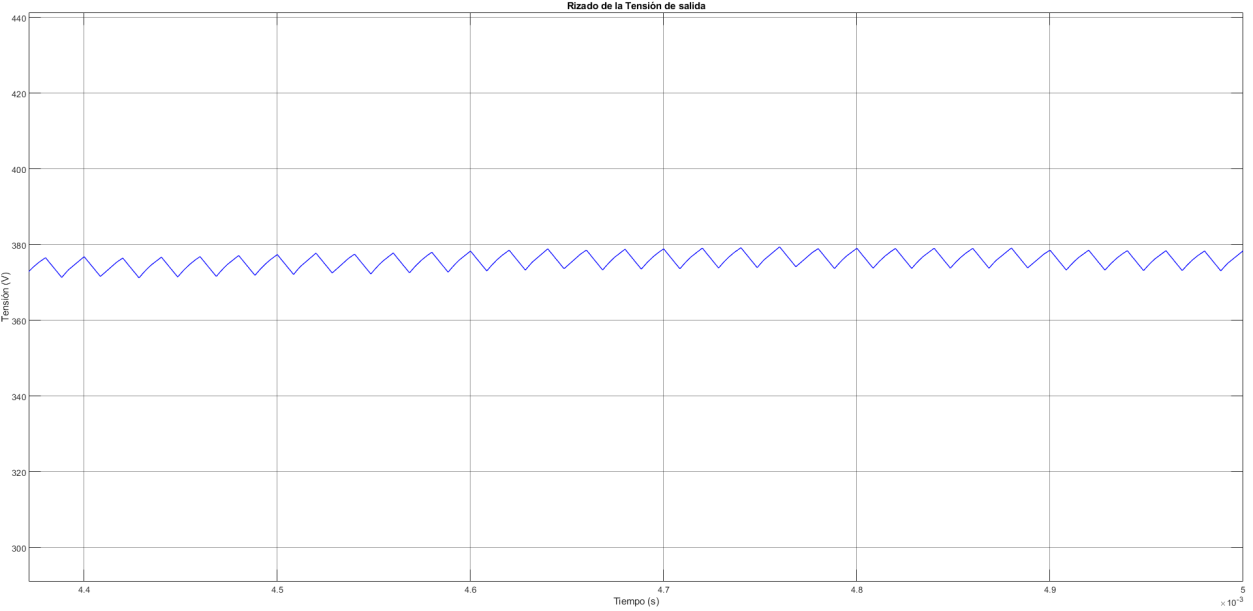
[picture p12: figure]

Figura 11. Medida del rizado de la tensión de salida en régimen permanente.

El rizado pico a pico de tensión es:

∆Vout = 378,095 − 373,226 = 4,870 V | (55)

Este valor es inferior al límite de 7,6 V establecido durante el dimensionado del

condensador de salida, por lo que cumple el criterio de diseño adoptado

El sobreimpulso observado en la tensión de salida durante el arranque es un efecto

transitorio habitual en este tipo de sistemas y no afecta al funcionamiento en régimen

permanente. No obstante, en una implementación real este comportamiento podría evitarse

mediante estrategias de control o mediante un arranque progresivo del convertidor.

En conjunto, estos resultados permiten validar el diseño del convertidor y confirman que

el modelo desarrollado en Simulink reproduce de forma adecuada el comportamiento

esperado del sistema.

### 6.3. Implementación del algoritmo MPPT en simulación

Una vez comprobado el funcionamiento del convertidor en lazo abierto, el siguiente paso

es adaptar el modelo para poder introducir el sistema de control. El objetivo es implementar

posteriormente un algoritmo MPPT, por lo que es necesario modificar primero la forma en la

que se controla el interruptor.

En la versión inicial del modelo, el MOSFET se controlaba mediante un bloque tipo Pulse

Generator, que generaba directamente una señal con un ciclo de trabajo fijo. Este

planteamiento es útil para analizar el comportamiento básico del convertidor, pero tiene una limitación clara, pues el ciclo de trabajo queda fijado dentro del propio bloque y no se puede

modificar durante la simulación.

Para poder aplicar un control más adelante, es necesario que ese valor pueda cambiarse

de forma externa. Se ha sustituido el generador de pulsos por una estructura de modulación

PWM construida con bloques básicos de Simulink.

El ciclo de trabajo deja de estar definido dentro de un bloque cerrado y pasa a ser una

variable que se puede ajustar directamente. Esto no modifica el funcionamiento del

convertidor, pero sí facilita que más adelante se pueda actuar sobre él desde un algoritmo de

control.

Después de realizar la modificación se ha comprobado que el comportamiento del sistema

se mantiene prácticamente igual. La tensión de salida sigue alcanzando valores próximos a

los esperados y la corriente de la inductancia presenta la forma característica del

funcionamiento en conducción continua. Esto indica que el cambio realizado afecta

únicamente a la forma de generar la señal de control, pero no a la etapa de potencia.

En este punto todavía no se ha implementado el algoritmo MPPT, pero el modelo ya está

preparado para ello. El ciclo de trabajo se podrá ajustar de forma dinámica en función de las

condiciones de funcionamiento del sistema.

### 6.3.1. Implementación del algoritmo P&O

Una vez preparada la estructura de control mediante la generación de la señal PWM, el

siguiente paso ha sido implementar el algoritmo de seguimiento del punto de máxima

potencia. Se ha utilizado el método de perturbación y observación (P&O), descrito

previamente en el capítulo 5.

El primer cambio necesario ha sido medir las variables del generador fotovoltaico. En el

modelo se obtiene la tensión y la corriente de entrada del convertidor, a partir de las cuales

se calcula la potencia instantánea mediante el producto de ambas magnitudes. Esta señal de

potencia es la referencia principal que utiliza el algoritmo para decidir cómo debe actuar sobre

el sistema.

Se han calculado las variaciones de potencia y de tensión entre dos instantes

consecutivos a partir de las medidas de entrada. Se han utilizado bloques de retardo (Unit

Delay), que permiten almacenar el valor anterior de cada variable, y posteriormente obtener

la diferencia respecto al valor actual. El sistema puede evaluar si el último cambio realizado

ha provocado un aumento o una disminución de la potencia.

La lógica del algoritmo P&O se ha implementado mediante un bloque MATLAB Function,

en el que se define el comportamiento del control. En cada iteración el algoritmo analiza el signo de variaciones de potencia y tensión y decide si debe aumentar o disminuir el ciclo de

trabajo. Si la potencia aumenta, el sistema continúa en la misma dirección de ajuste. En caso

contrario, invierte el sentido de la perturbación. Este proceso se repite de forma continua

durante la simulación permitiendo que el punto de funcionamiento se desplace hacia zona de

máxima potencia.

El ciclo de trabajo calculado por el algoritmo se aplica directamente al generador PWM

implementado en el apartado anterior. El control actúa sobre el convertidor modificando el

tiempo de conducción del MOSFET y, por tanto, el punto de operación del generador

fotovoltaico.

Para evitar valores no válidos del ciclo de trabajo, se ha añadido un bloque de saturación

que limita su rango dentro de valores razonables. Esto resulta necesario para evitar

situaciones no físicas o problemas de estabilidad en la simulación.

Durante la implementación también ha sido necesario introducir retardos adicionales en

determinadas señales para eliminar lazos algebraicos, lo que permite que el modelo se

resuelva correctamente en Simulink sin generar errores.

En la Figura 12 se muestra el esquema completo del sistema con el algoritmo MPPT

integrado.

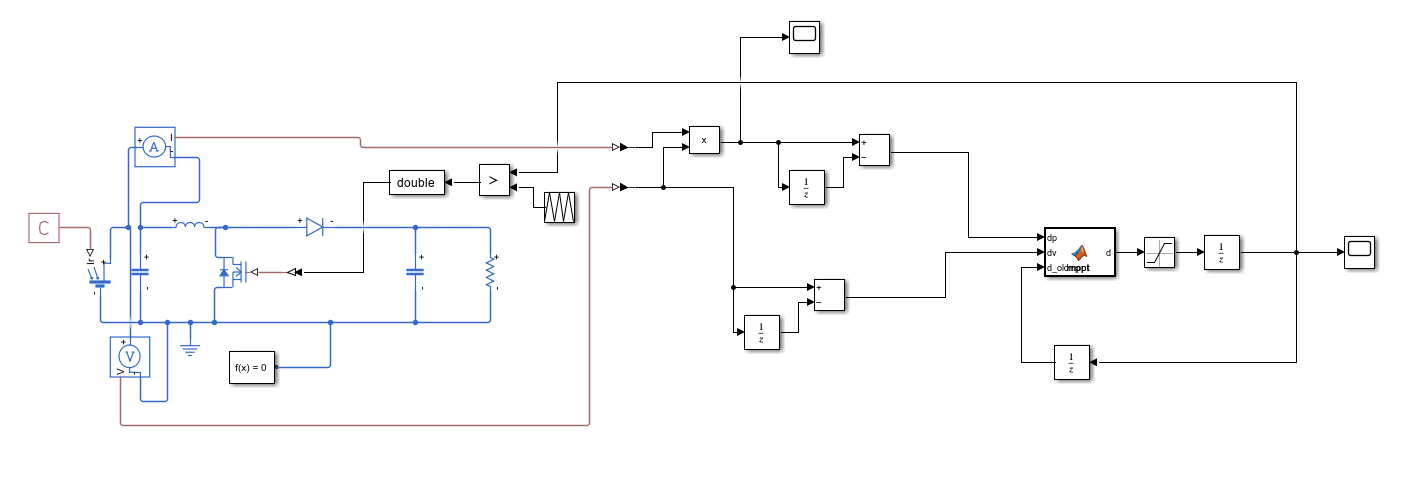
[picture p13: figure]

Figura 12. Esquema del convertidor Boost con control MPPT implementado

### 6.3.2. Integración del control en el sistema

Una vez implementado el algoritmo el sistema pasa a funcionar en lazo cerrado. A

diferencia del caso anterior, en el que el ciclo de trabajo permanecía fijo, ahora este se ajusta

de forma automática en función de la potencia generada.

Este cambio se traduce en un comportamiento diferente del convertidor. El sistema ya no

opera en un punto de funcionamiento impuesto, sino que lo va corrigiendo de forma continua

para acercarse al punto de máxima potencia del generador.

En la figura 13 se muestra la evolución de la potencia generada por el sistema.

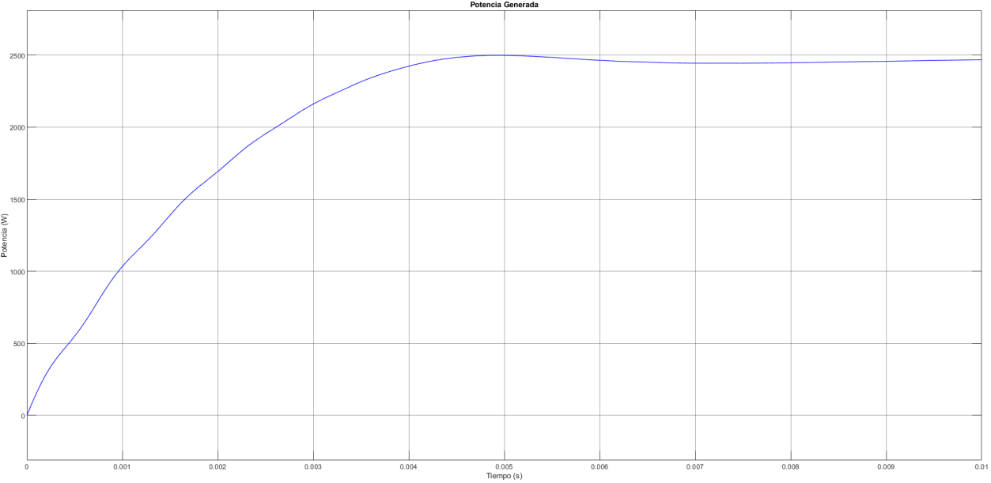
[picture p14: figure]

Figura 13. Evolución de la potencia generada con MPPT

La potencia aumenta desde el arranque hasta alcanzar un valor próximo al máximo

disponible, en torno a 2,4-2,5 kW. Una vez alcanzada esta zona la señal presenta pequeñas

oscilaciones alrededor del valor máximo. Este comportamiento es característico del método

P&O, pues el algoritmo introduce perturbaciones constantes para comprobar en qué dirección

debe ajustar el sistema [11].

Durante esta etapa se observó la aparición de rizado en la señal de entrada, lo que

afectaba notoriamente a la estabilidad de las medidas de tensión y corriente utilizadas por el

algoritmo MPPT. Este efecto puede provocar en el cálculo de la potencia presente pequeñas

variaciones no deseadas dificultando el correcto seguimiento del punto de máxima potencia.

Para reducir este efecto se ha añadido un condensador en la entrada del convertidor

de 100 µF, cuya función es filtrar la tensión de entrada y disminuir su rizado. Con esta

modificación las señales medidas resultan más estables, lo que permite mejorar el

comportamiento del algoritmo sin alterar el funcionamiento general del sistema.

En la Figura 14 se muestra la evolución del ciclo de trabajo mediante P&O.

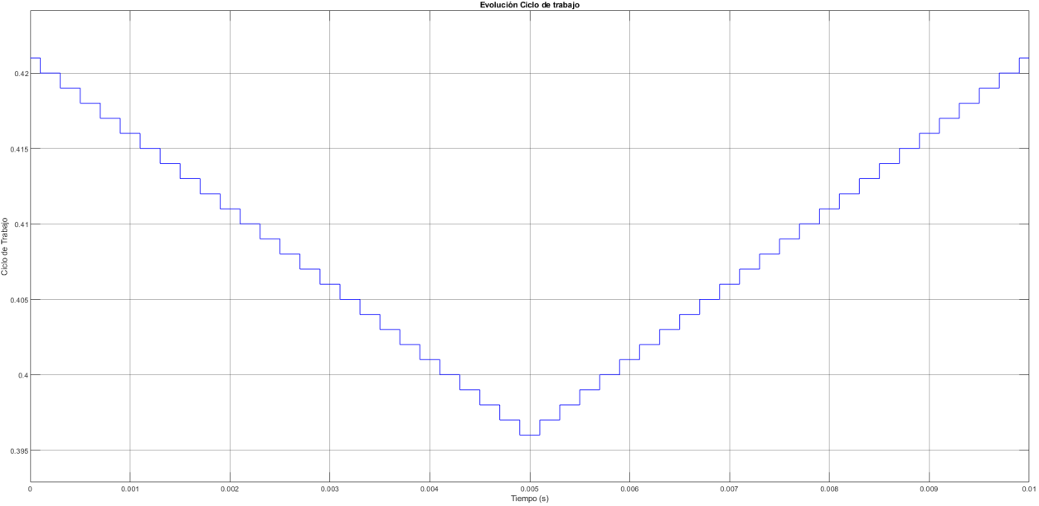
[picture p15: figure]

Figura 14. Evolución del ciclo de trabajo del convertidor

El ciclo de trabajo no permanece constante, sino que se ajusta progresivamente hasta

situarse en un entorno de funcionamiento estable. Las pequeñas variaciones que se aprecian

corresponden al propio funcionamiento del algoritmo que oscila ligeramente alrededor del

punto, entre un poco más de 0,42 y un poco más de 0,395.

En la Figura 15 se muestra la tensión de salida del convertidor en estas condiciones.

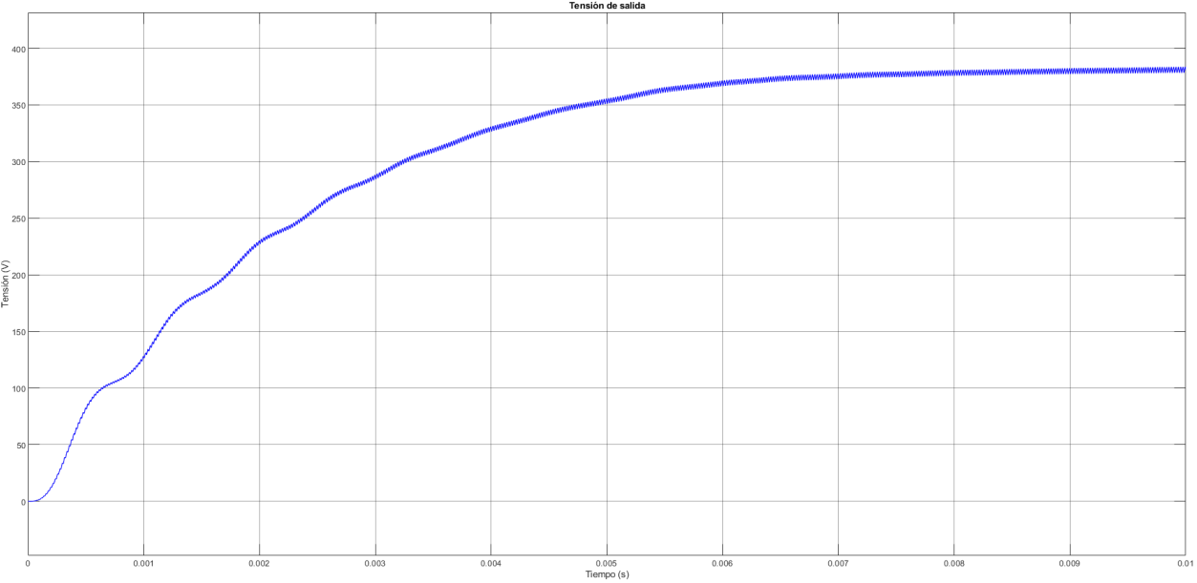
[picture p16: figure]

Figura 15. Tensión de salida del convertidor con MPPT

La tensión alcanza valores próximos a los obtenidos anteriormente, aunque ahora su

evolución está condicionada por la acción del algoritmo de control. A pesar de las pequeñas variaciones introducidas por el MPPT, el sistema mantiene un comportamiento estable lo que

confirma el correcto funcionamiento del modelo en lazo cerrado.

En la figura 16 se muestra la evolución temporal de la corriente de la inductancia en

estas condiciones.

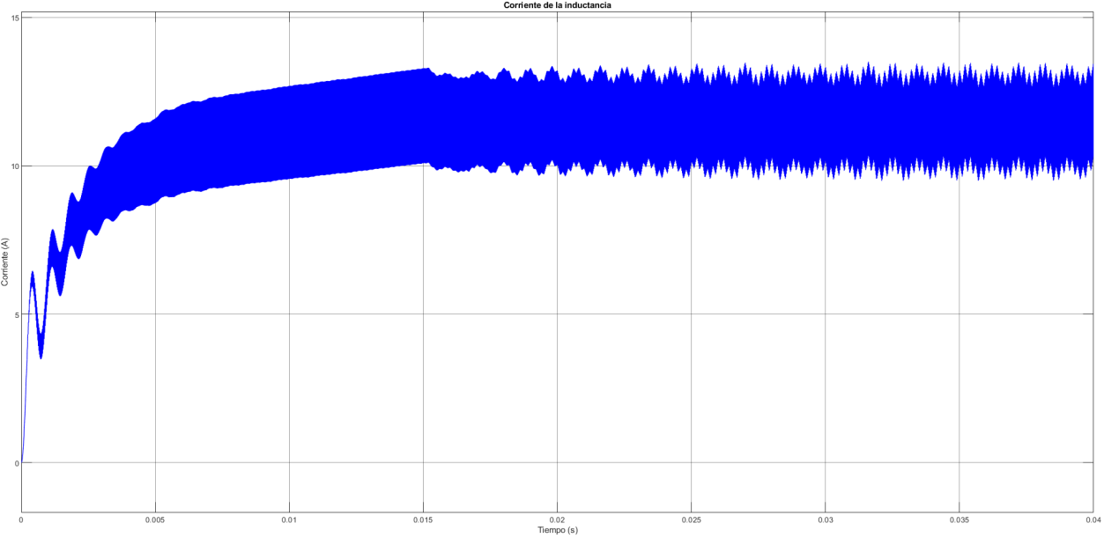
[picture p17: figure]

Figura 16. Corriente de la inductancia con control MPPT

La corriente presenta un comportamiento similar al observado en la simulación en lazo

abierto, aunque en este caso su valor medio no es contante durante el transitorio inicial, sino

que aumenta progresivamente a medida que el algoritmo MPPT ajusta el punto de

funcionamiento del sistema.

Al ampliar el tiempo de simulación se observa que, a partir de aproximadamente 0,015 s,

la corriente entra en una zona de funcionamiento estable y su valor medio se mantiene

alrededor de 11-12 A. La banda que aparece en la gráfica se debe principalmente al rizado

provocado por la conmutación del convertidor.

Además, el algoritmo P&O continúa introduciendo pequeñas variaciones en el ciclo de

trabajo incluso después de alcanzar el entrono del punto de máxima potencia. Esto provoca

ligeras oscilaciones en el valor medio de la corriente, pero no indica que el sistema sea

inestable, sino que forma parte del funcionamiento normal del método empleado.

En estas condiciones el convertidor continúa operando en modo de conducción continúa

pues la corriente de la inductancia n llega a anularse durante ningún instante.

### 6.4. Análisis ante variaciones de irradiancia

Con el objetivo de comprobar el comportamiento del sistema en condiciones más

próximas a un caso real, se ha introducido una variación en la irradiancia del generador

fotovoltaico durante la simulación. Se ha utilizado un bloque tipo Step que provoca un cambio de 1000 W/m² a 600 W/m² en el instante t = 0,005 s.

Este tipo de perturbación permite analizar si el algoritmo MPPT es capaz de adaptarse a

cambios bruscos en las condiciones de operación, pues una variación de la irradiancia implica

directamente un desplazamiento del punto de máxima potencia del generador.

En la Figura 17 se muestra la evolución de la potencia generada.

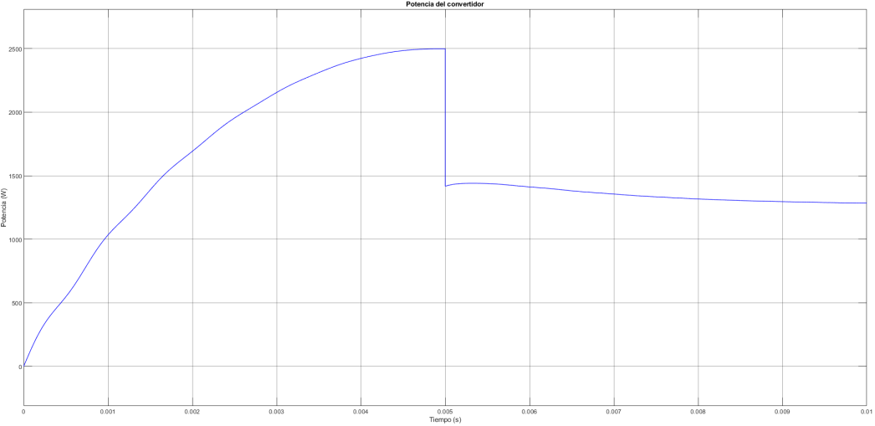
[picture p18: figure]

Figura 17. Evolución de la potencia generada ante un cambio de irradiancia

Durante la primera parte de la simulación la potencia aumenta progresivamente hasta

alcanzar valores cercanos a 2,5 kW, lo cual coincide con el punto de máxima potencia para

la irradiancia inicial. En el instante en el que se produce el cambio se observa una caída

prácticamente instantánea de la potencia hasta valores en torno a 1,4-1,5 kW. Este

comportamiento confirma que la potencia generada depende directamente de la irradiancia

disponible por lo que la reducción observada es coherente con la disminución de energía

incidente sobre el generador.

Después de la caída inicial, se aprecia que la potencia no permanece constante, sino

que presenta una ligera evolución hasta estabilizarse. Esto indica que el MPPT actúa tras el

cambio y comienza a ajustar el punto de operación hasta encontrar el nuevo máximo

disponible. Las pequeñas oscilaciones que aparecen en régimen permanente son propias del

método P&O, ya que el algoritmo necesita perturbar continuamente el sistema para verificar

si se mantiene en el entorno de punto óptimo [11].

En la Figura 18 se muestra la evolución del ciclo de trabajo.

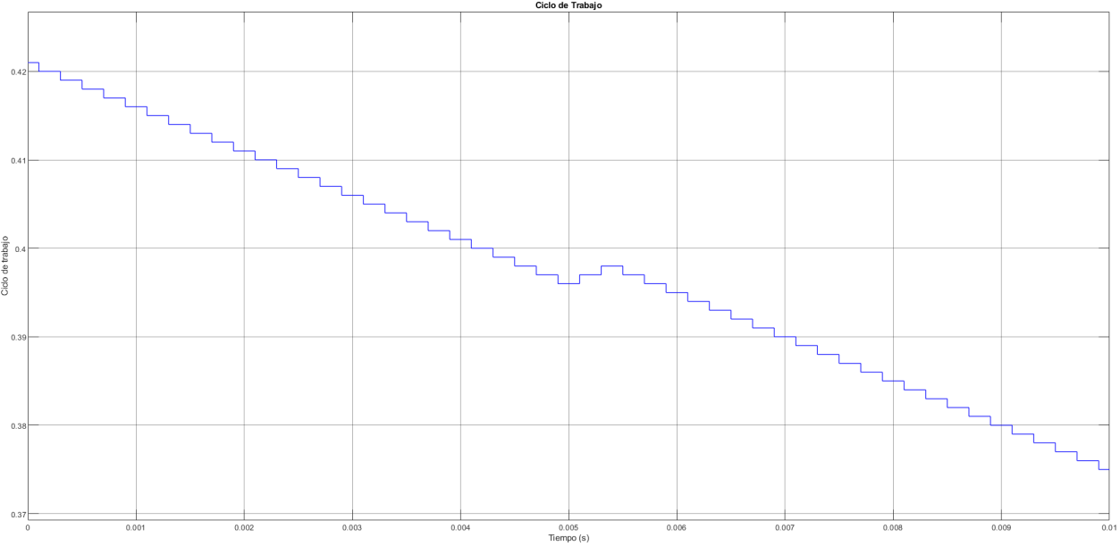
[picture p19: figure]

Figura 18. Evolución del ciclo de trabajo ante un cambio de irradiancia.

Antes del cambio de irradiancia el ciclo de trabajo presenta una tendencia

descendente suave correspondiente al proceso de búsqueda del punto de máxima potencia.

Sin embargo, en el instante en el que se produce la perturbación se observa una modificación

clara en su evolución. El algoritmo cambia de dirección de ajuste y continúa variando el ciclo

de trabajo hasta adaptarse a las nuevas condiciones. La evolución en forma de escalones es

característica del método de perturbación y observación pues el algoritmo modifica el ciclo de

trabajo en incrementos discretos en cada iteración.

Este comportamiento es coherente con el funcionamiento del método P&O. Al

producirse una variación brusca en la potencia, el algoritmo interpreta que el punto de

operación ya no es óptimo y comienza un nuevo proceso de búsqueda. El hecho de que el

ciclo de trabajo presente pequeñas variaciones en vez de estabilizarse confirma que el

sistema está operando en el entorno de máxima potencia. Se observa además una tendencia

global descendente del ciclo de trabajo, lo que indica que el nuevo punto de máxima potencia

se alcanza con una relación de conversión diferente a la condición inicial.

En la Figura 19 se muestra la tensión de salida del convertidor.

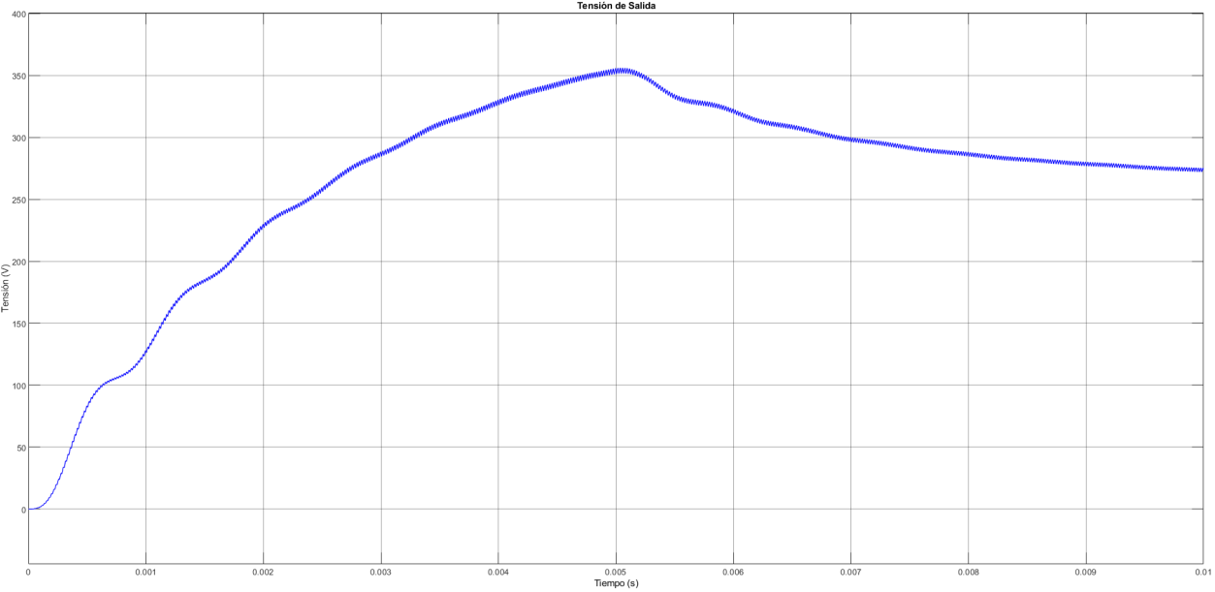
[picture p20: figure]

Figura 19. Tensión de salida ante un cambio de irradiancia.

La tensión de salida presenta un comportamiento más suave que la potencia. Durante

la primera parte de la simulación aumenta hasta alcanzar un valor próximo al esperado. Tras

el cambio de irradiancia se observa un pequeño sobreimpulso seguido de una disminución

progresiva hasta un nuevo valor de régimen.

Esta disminución de la tensión no debe interpretarse como un fallo del convertidor ni

del algoritmo MPPT. En esta simulación la salida del convertidor se representa mediante una

carga resistiva de 60 Ω. Al reducirse la irradiancia también disminuye la potencia disponible

en el generador fotovoltaico y como el valor de la carga se mantiene constante, se modifican

las variables de salida del convertidor. Al haber menos energía disponible, el sistema se

adapta a un nuevo punto de funcionamiento y la tensión de salida se estabiliza en un valor

inferior.

En una aplicación real de carga de baterías esta situación se gestionaría mediante la

propia batería y la estrategia de carga CC-CV. Es decir, una reducción de la irradiancia no

implica necesariamente que el proceso de carga se detenga, sino que la potencia disponible

para cargar sería menor. En ese caso lo más habitual sería que la corriente de carga

disminuyera y que el proceso continuara de forma más lenta, siempre que se respeten los

límites de tensión y corriente.

Por tanto, la caída observada en la tensión de salida está relacionada con el modelo

de carga utilizado y con la disminución de potencia disponible. La simulación permite

comprobar que el MPPT responde ante el cambio de irradiancia y desplaza el punto de

operación del convertidor, aunque no representa todavía una regulación completa de la

tensión de carga de una batería real.

En la Figura 20 se muestra la corriente de la inductancia.

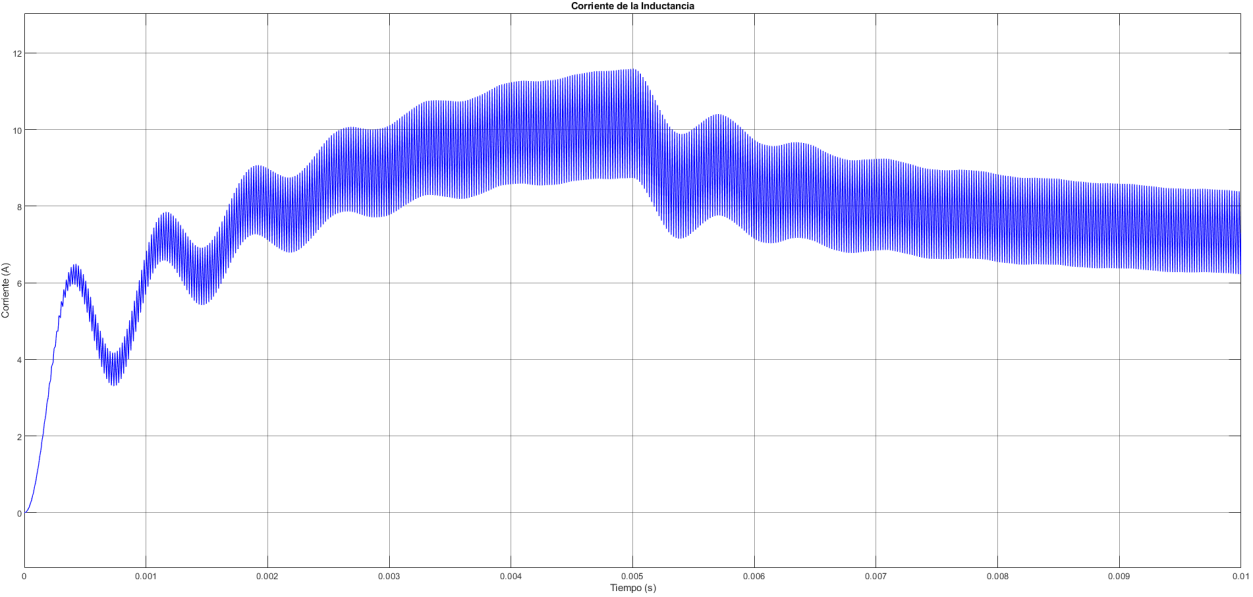
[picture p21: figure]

Figura 20. Corriente de la inductancia ante un cambio de irradiancia

La corriente de la inductancia refleja de forma bastante clara el efecto del cambio de

irradiancia. Antes de la perturbación el valor medio se sitúa en torno a 10-11 A. Tras el cambio,

se observa una reducción progresiva hasta valores cercanos a 8-9 A, lo cual es coherente

con la disminución de la potencia generada.

Se mantiene el rizado característico del convertidor, lo que indica que el sistema

continúa operando en modo de conducción continua. Durante el transitorio se aprecia una

ligera variación en la amplitud del rizado debido a los cambios en el ciclo de trabajo y en el

punto de operación.

Desde el punto de vista de la carga, esta reducción de corriente también resulta

coherente. Si la irradiancia disminuye, el generador fotovoltaico no puede entregar la misma

potencia que en condiciones nominales. Por tanto, en un sistema real, la batería recibe menos

corriente de carga y el proceso es más lento. La estrategia CC-CV es la encargada de limitar

la tensión y corriente para mantener la carga dentro de condiciones seguras para la batería

del vehículo.

Aunque el punto de máxima potencia también depende de la temperatura del módulo

fotovoltaico, en este trabajo se ha analizado únicamente la variación de la irradiancia, al ser

el factor que produce más cambios significativos en la potencia generada y permite evaluar

de forma clara el comportamiento del algoritmo MPPT.

Los resultados obtenidos no sólo validan el funcionamiento del algoritmo MPPT, sino

que confirman que el sistema es capaz de adaptarse de forma estable a cambios en las condiciones de operación, manteniendo un comportamiento coherente con el análisis teórico

realizado en capítulos anteriores.

## 7. Análisis de los resultados

El objetivo es entender qué está pasando en el sistema y comprobar si el comportamiento

coincide con lo que se esperaba en el diseño.

Se revisan los valores principales obtenidos en simulación y se comenta cómo responde

el convertidor, tanto en condiciones normales como cuando se introducen cambios en la

irradiancia.
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

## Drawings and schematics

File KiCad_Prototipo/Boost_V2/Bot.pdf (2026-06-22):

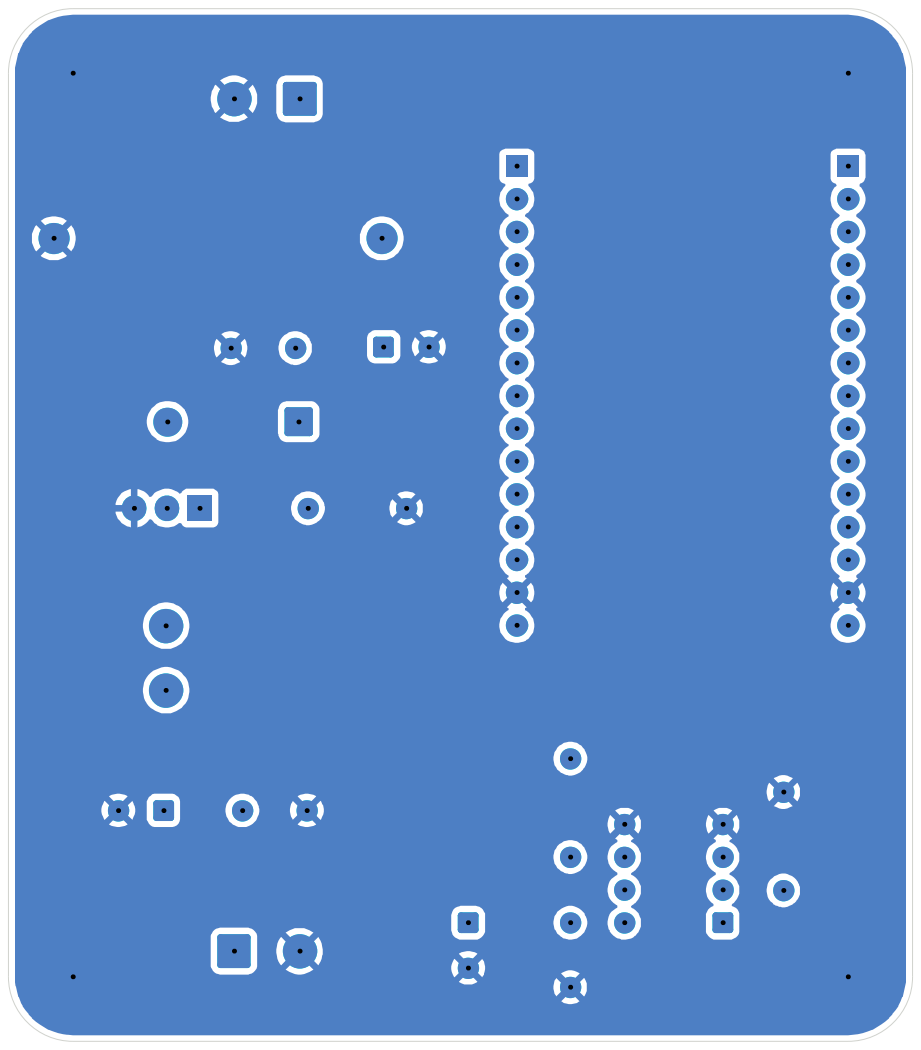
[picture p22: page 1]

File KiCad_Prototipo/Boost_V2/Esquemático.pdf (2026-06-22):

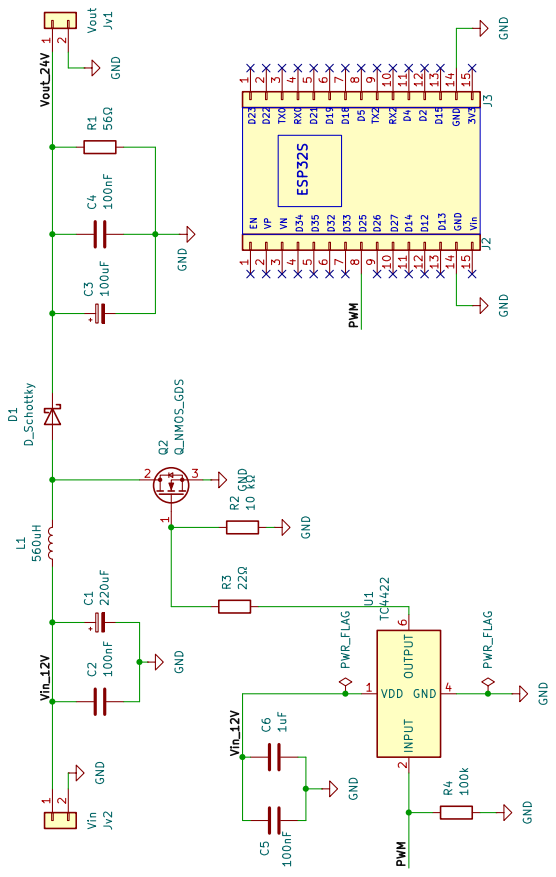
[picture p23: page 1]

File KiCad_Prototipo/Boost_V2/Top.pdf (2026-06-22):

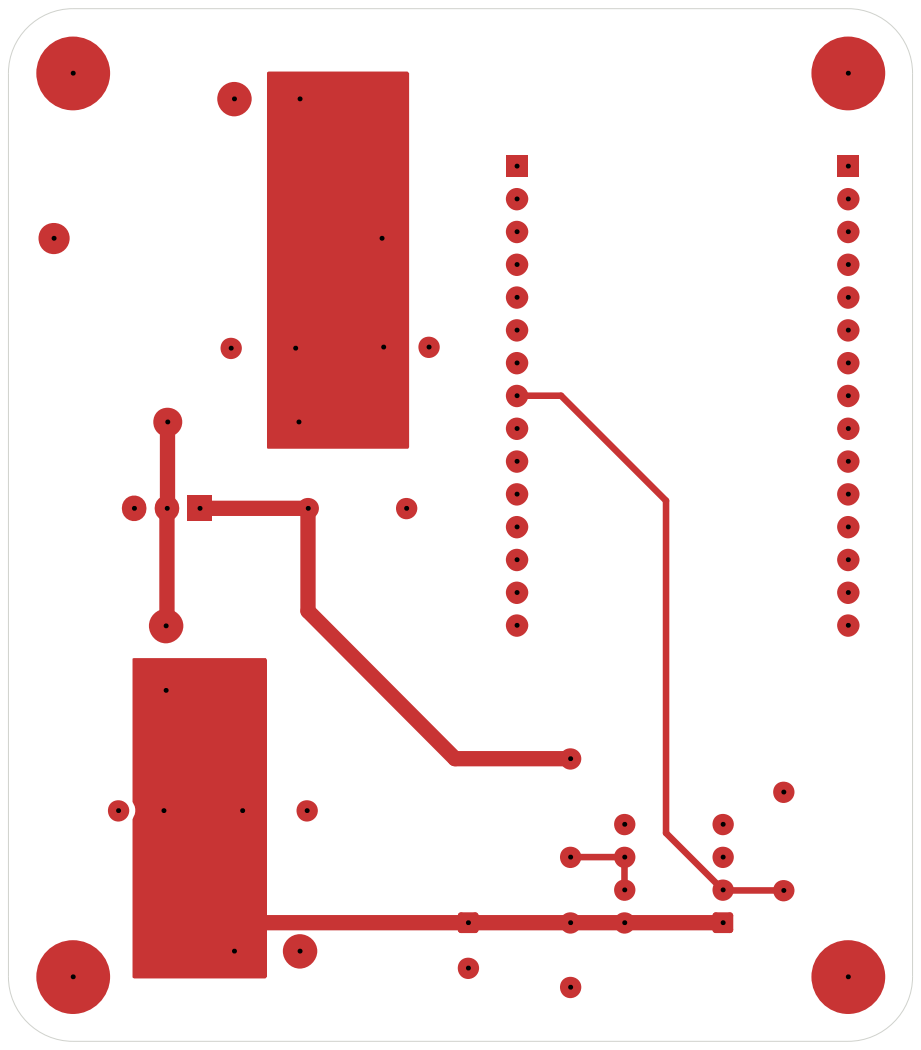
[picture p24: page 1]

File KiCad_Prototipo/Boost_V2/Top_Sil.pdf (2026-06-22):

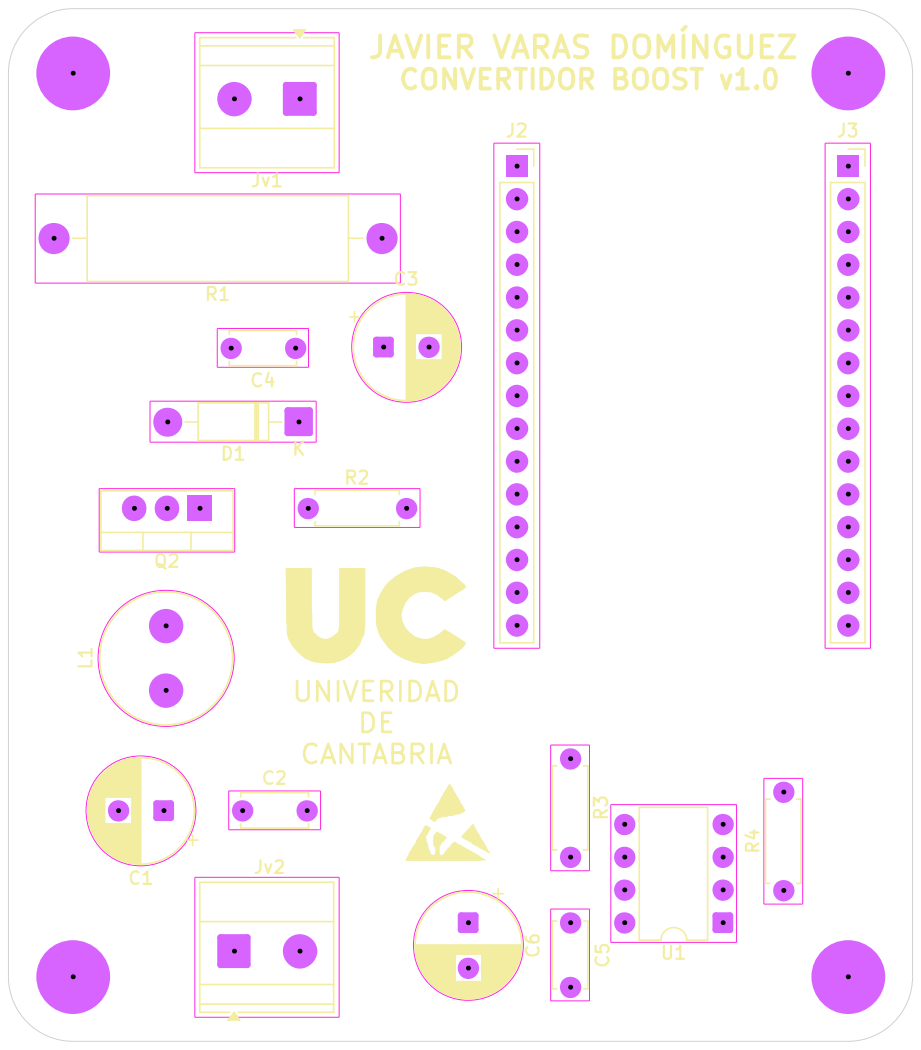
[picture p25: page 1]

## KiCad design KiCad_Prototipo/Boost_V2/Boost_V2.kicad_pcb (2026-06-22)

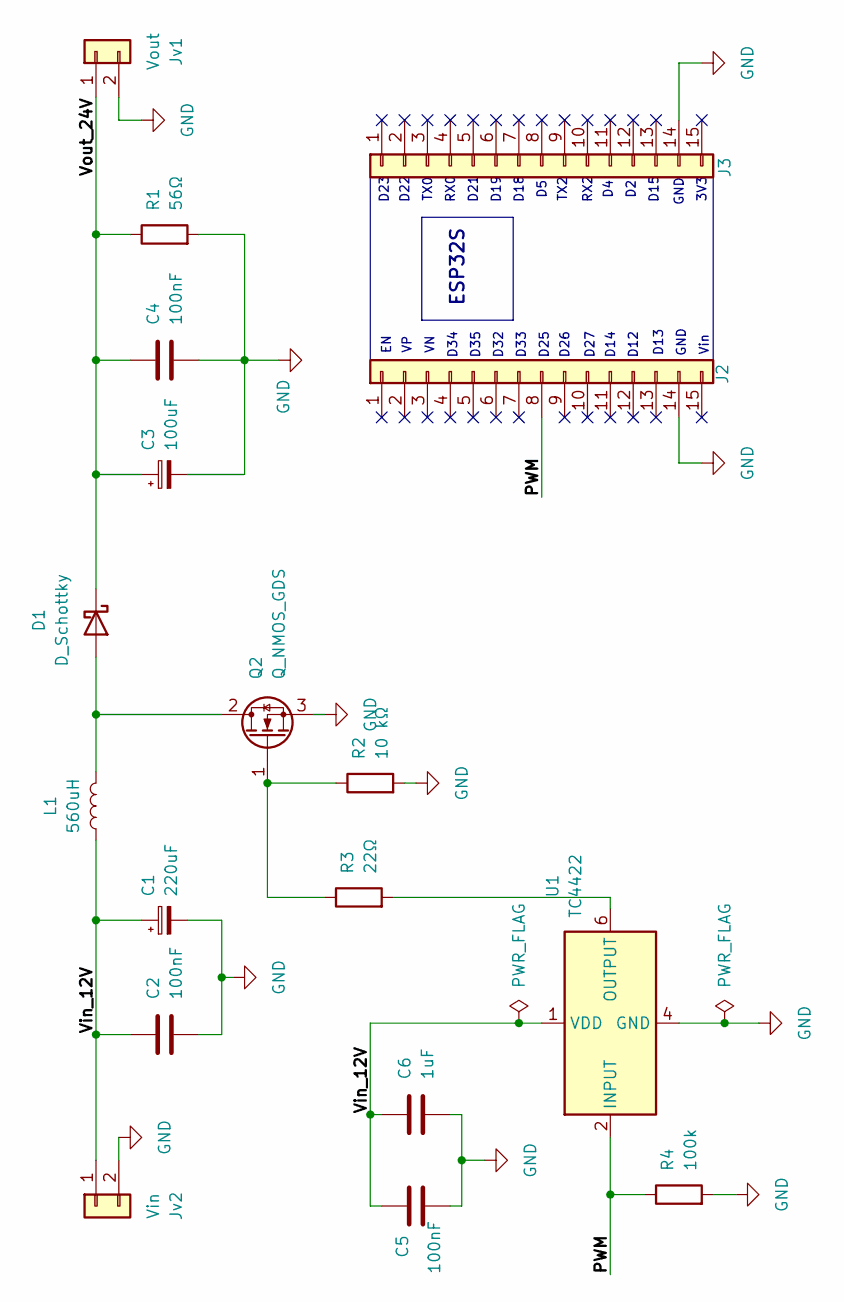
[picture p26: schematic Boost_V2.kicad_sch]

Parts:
C1: 220uF; CP_Radial_D8.0mm_P3.50mm
C2, C4, C5: 100nF; C_Disc_D5.0mm_W2.5mm_P5.00mm
C3: 100uF; CP_Radial_D8.0mm_P3.50mm
C6: 1uF; CP_Radial_D8.0mm_P3.50mm
D1: D_Schottky; D_DO-41_SOD81_P10.16mm_Horizontal
J2, J3: Conn_01x15; PinSocket_1x15_P2.54mm_Vertical
Jv1: Vout; TerminalBlock_Phoenix_MKDS-1,5-2-5.08_1x02_P5.08mm_Horizont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
Jv2: Vin; TerminalBlock_Phoenix_MKDS-1,5-2-5.08_1x02_P5.08mm_Horizont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
L1: 560uH; L_Radial_D10.0mm_P5.00mm_Fastron_07M
Q2: Q_NMOS_GDS; TO-220-3_Vertical
R1: 56Ω; R_Axial_Power_L20.0mm_W6.4mm_P25.40mm
R2: 10 kΩ; R_Axial_DIN0207_L6.3mm_D2.5mm_P7.62mm_Horizontal
R3: 22Ω; R_Axial_DIN0207_L6.3mm_D2.5mm_P7.62mm_Horizontal
R4: 100k; R_Axial_DIN0207_L6.3mm_D2.5mm_P7.62mm_Horizontal
U1: TC4422; DIP-8_W7.62mm

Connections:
/PWM: J2.8, R4.1, U1.2 (INPUT)
/Vin_12V: C1.1, C2.1, C5.1, C6.1, Jv2.1, L1.1, U1.1 (VDD), U1.8 (VDD)
/Vout_24V: C3.1, C4.1, D1.1 (K), Jv1.1, R1.1
GND: C1.2, C2.2, C3.2, C4.2, C5.2, C6.2, J2.14, J3.14 (Pin_14_14), Jv1.2, Jv2.2, Q2.3 (S), R1.2, R2.2, R4.2, U1.4 (GND), U1.5 (GND)
unnamed: D1.2 (A), L1.2, Q2.2 (D)
unnamed: Q2.1 (G), R2.1, R3.1
unnamed: R3.2, U1.6 (OUTPUT), U1.7 (OUTPUT)

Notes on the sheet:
D34
TX0
D27
D26
3V3
D12
D14
D33
D21
GND
D32
RX0
D23
GND
D25
D18
Vin
D35
RX2
D15
D13
TX2
D19
D22
ESP32S

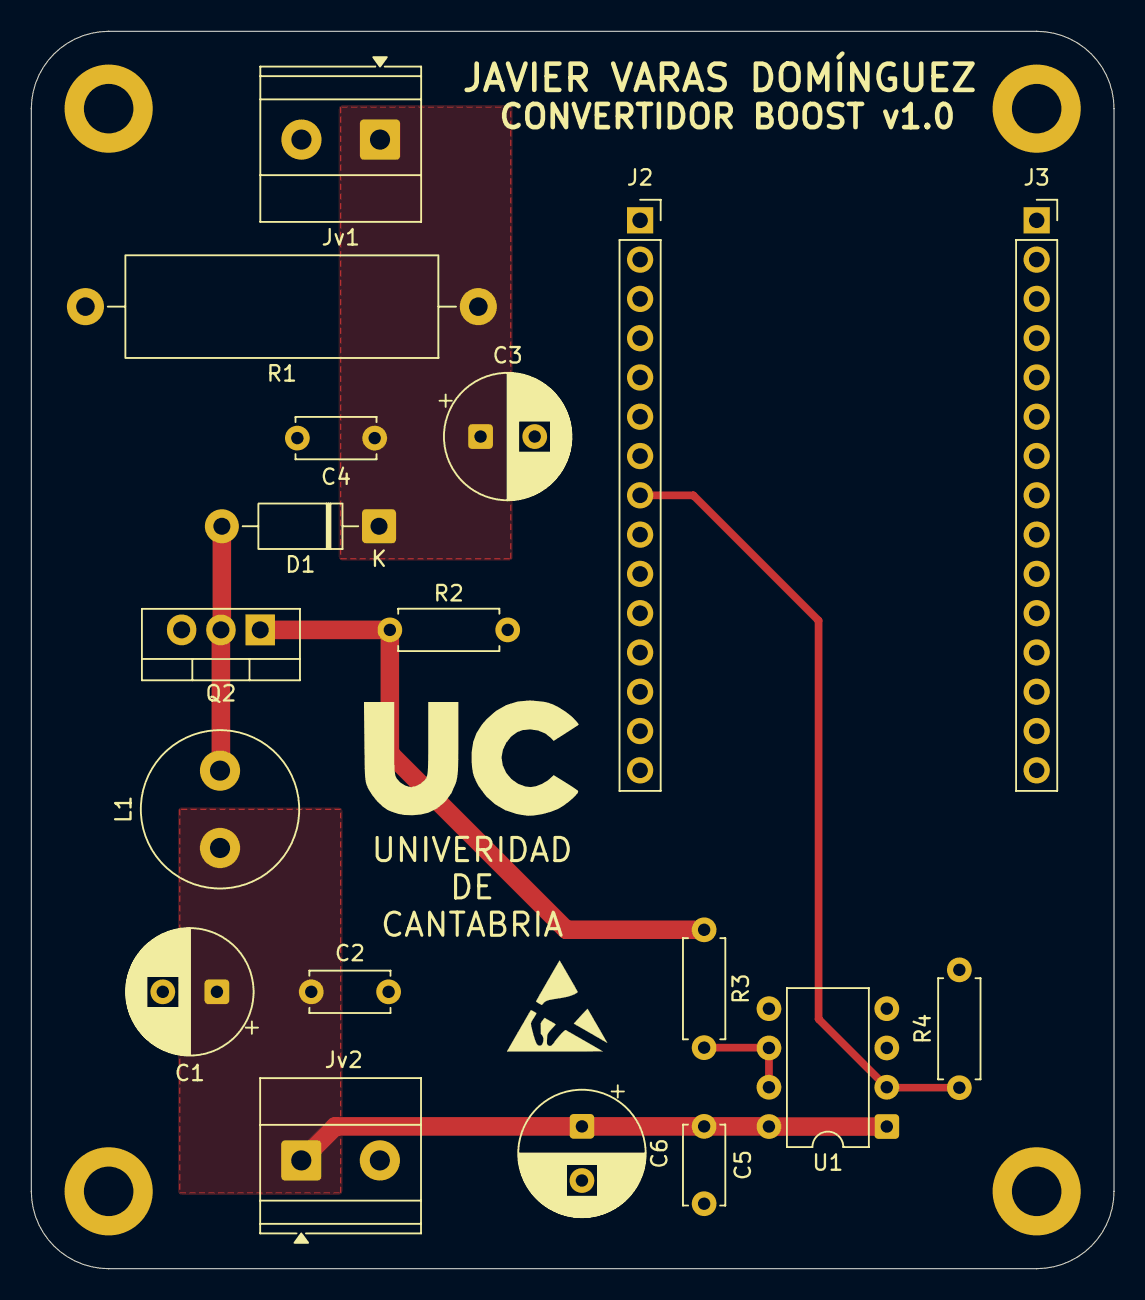
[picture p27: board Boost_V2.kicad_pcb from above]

Board: 2 copper layers, 70.0 x 80.0 mm, 18 parts (0 on the bottom side), 7 nets.

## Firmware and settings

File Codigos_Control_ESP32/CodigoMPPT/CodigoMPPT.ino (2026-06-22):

#include <Arduino.h>

/*
  CONTROL MPPT P&O PARA CONVERTIDOR BOOST CON ESP32

  PWM:
  GPIO25 -> INPUT del TC4422

  Medida de tension de entrada:
  Vin_12V -> R5 = 33 kOhm -> GPIO34 -> R6 = 8.2 kOhm -> GND

  Medida de corriente de entrada:
  Pin 2 del conector Vin -> R_shunt -> GND de la placa
  GPIO35 conectado al lado izquierdo de R_shunt

  Comandos por monitor serie:
  start  -> iniciar MPPT
  stop   -> detener convertidor
  status -> mostrar medidas
  cal    -> recalibrar cero de corriente
*/

// PINES
const int PWM_PIN = 25;
const int VIN_ADC_PIN = 34;
const int SHUNT_ADC_PIN = 35;

// PWM
const int PWM_FREQUENCY_HZ = 50000;
const int PWM_RESOLUTION_BITS = 10;
const int PWM_MAX_VALUE = 1023;

// DIVISOR DE TENSION DE ENTRADA
const float VIN_R1_OHM = 33000.0;
const float VIN_R2_OHM = 8200.0;

const float VIN_DIVIDER_FACTOR =
  (VIN_R1_OHM + VIN_R2_OHM) / VIN_R2_OHM;


// RESISTENCIA SHUNT
// Cambiar este valor /////////////
const float SHUNT_RESISTANCE_OHM = 0.47;

// PARAMETROS DEL MPPT
const float MPPT_STEP = 0.001;
const float DUTY_INITIAL = 0.10;
const float DUTY_MIN = 0.05;
const float DUTY_MAX = 0.60;

const unsigned long MPPT_PERIOD_MS = 200;

// PROTECCIONES
const float MIN_INPUT_VOLTAGE_V = 1.0;
const float MAX_INPUT_VOLTAGE_V = 15.0;

// Con shunt de 0.47 Ohm
const float MAX_INPUT_CURRENT_A = 1.20;

// FILTRADO DE MEDIDAS
const int ADC_SAMPLES = 50;


// VARIABLES GLOBALES
float duty = 0.0;

float vin = 0.0;
float iin = 0.0;
float pin = 0.0;

float vinPrevious = 0.0;
float pinPrevious = 0.0;

float shuntOffsetVoltage = 0.0;

bool mpptRunning = false;
bool firstMeasurement = true;

unsigned long lastMpptTime = 0;
unsigned long lastPrintTime = 0;

// FUNCION PARA APLICAR DUTY
void setDuty(float newDuty)
{
  if (newDuty < 0.0)
  {
    newDuty = 0.0;
  }

  if (newDuty > DUTY_MAX)
  {
    newDuty = DUTY_MAX;
  }

  duty = newDuty;

  int pwmValue = (int)(duty * PWM_MAX_VALUE);

  ledcWrite(PWM_PIN, pwmValue);
}
// LECTURA FILTRADA ADC EN VOLTIOS
float readAdcVoltage(int pin)
{
  unsigned long sumMillivolts = 0;

  for (int i = 0; i < ADC_SAMPLES; i++)
  {
    sumMillivolts += analogReadMilliVolts(pin);
    delayMicroseconds(100);
  }

  float averageMillivolts =
    (float)sumMillivolts / ADC_SAMPLES;

  return averageMillivolts / 1000.0;
}
// CALIBRAR CERO DE CORRIENTE
void calibrateCurrentOffset()
{
  setDuty(0.0);

  delay(500);

  float sumVoltage = 0.0;

  for (int i = 0; i < 100; i++)
  {
    sumVoltage += readAdcVoltage(SHUNT_ADC_PIN);
    delay(5);
  }

  shuntOffsetVoltage = sumVoltage / 100.0;

  Serial.print("Offset shunt = ");
  Serial.print(shuntOffsetVoltage, 6);
  Serial.println(" V");
}

// MEDIR TENSION, CORRIENTE Y POTENCIA
void readMeasurements()
{
  float vinAdcVoltage = readAdcVoltage(VIN_ADC_PIN);

  vin = vinAdcVoltage * VIN_DIVIDER_FACTOR;

  float shuntAdcVoltage = readAdcVoltage(SHUNT_ADC_PIN);

  float shuntVoltage =
    shuntAdcVoltage - shuntOffsetVoltage;

  if (shuntVoltage < 0.0)
  {
    shuntVoltage = 0.0;
  }

  iin = shuntVoltage / SHUNT_RESISTANCE_OHM;

  pin = vin * iin;
}

// COMPROBAR SEGURIDAD
bool measurementsAreSafe()
{
  if (vin < MIN_INPUT_VOLTAGE_V)
  {
    Serial.println("ERROR: Vin demasiado baja.");
    return false;
  }

  if (vin > MAX_INPUT_VOLTAGE_V)
  {
    Serial.println("ERROR: Vin demasiado alta.");
    return false;
  }

  if (iin > MAX_INPUT_CURRENT_A)
  {
    Serial.println("ERROR: sobrecorriente.");
    return false;
  }

  return true;
}

// DETENER CONVERTIDOR
void stopConverter()
{
  mpptRunning = false;
  firstMeasurement = true;

  setDuty(0.0);

  Serial.println("Convertidor detenido.");
}

// ALGORITMO MPPT P&O
void runMppt()
{
  readMeasurements();

  if (!measurementsAreSafe())
  {
    stopConverter();
    return;
  }

  if (firstMeasurement)
  {
    vinPrevious = vin;
    pinPrevious = pin;

    firstMeasurement = false;

    return;
  }

  float dp = pin - pinPrevious;
  float dv = vin - vinPrevious;

  float newDuty = duty;

  if (dp > 0.0)
  {
    if (dv > 0.0)
    {
      newDuty = duty - MPPT_STEP;
    }
    else
    {
      newDuty = duty + MPPT_STEP;
    }
  }
  else
  {
    if (dv > 0.0)
    {
      newDuty = duty + MPPT_STEP;
    }
    else
    {
      newDuty = duty - MPPT_STEP;
    }
  }

  if (newDuty > DUTY_MAX)
  {
    newDuty = DUTY_MAX;
  }

  if (newDuty < DUTY_MIN)
  {
    newDuty = DUTY_MIN;
  }

  setDuty(newDuty);

  vinPrevious = vin;
  pinPrevious = pin;
}

// MOSTRAR ESTADO
void printStatus()
{
  Serial.print("Vin = ");
  Serial.print(vin, 3);
  Serial.print(" V | ");

  Serial.print("Iin = ");
  Serial.print(iin, 3);
  Serial.print(" A | ");

  Serial.print("Pin = ");
  Serial.print(pin, 3);
  Serial.print(" W | ");

  Serial.print("Duty = ");
  Serial.print(duty * 100.0, 2);
  Serial.println(" %");
}

// COMANDOS POR MONITOR SERIE
void readSerialCommand()
{
  if (!Serial.available())
  {
    return;
  }

  String command = Serial.readStringUntil('\n');

  command.trim();
  command.toLowerCase();

  if (command == "start")
  {
    readMeasurements();

    if (!measurementsAreSafe())
    {
      Serial.println("No se puede iniciar el MPPT.");
      return;
    }

    firstMeasurement = true;

    setDuty(DUTY_INITIAL);

    mpptRunning = true;

    Serial.println("MPPT iniciado.");
  }
  else if (command == "stop")
  {
    stopConverter();
  }
  else if (command == "status")
  {
    readMeasurements();
    printStatus();
  }
  else if (command == "cal")
  {
    if (mpptRunning)
    {
      Serial.println("Primero deten el MPPT con stop.");
    }
    else
    {
      calibrateCurrentOffset();
    }
  }
  else
  {
    Serial.println("Comandos disponibles:");
    Serial.println("start");
    Serial.println("stop");
    Serial.println("status");
    Serial.println("cal");
  }
}

// SETUP
void setup()
{
  Serial.begin(115200);

  delay(1000);

  pinMode(VIN_ADC_PIN, INPUT);
  pinMode(SHUNT_ADC_PIN, INPUT);

  analogReadResolution(12);

  analogSetPinAttenuation(VIN_ADC_PIN, ADC_11db);
  analogSetPinAttenuation(SHUNT_ADC_PIN, ADC_11db);

  bool pwmConfigured =
    ledcAttach(
      PWM_PIN,
      PWM_FREQUENCY_HZ,
      PWM_RESOLUTION_BITS
    );

  if (!pwmConfigured)
  {
    Serial.println("ERROR al configurar el PWM.");

    while (true)
    {
      delay(1000);
    }
  }

  setDuty(0.0);

  calibrateCurrentOffset();

  Serial.println();
  Serial.println("Sistema preparado.");
  Serial.println("Comandos disponibles:");
  Serial.println("start  -> iniciar MPPT");
  Serial.println("stop   -> detener");
  Serial.println("status -> ver medidas");
  Serial.println("cal    -> calibrar cero de corriente");
}

// LOOP
void loop()
{
  readSerialCommand();

  unsigned long currentTime = millis();

  if (
    mpptRunning &&
    currentTime - lastMpptTime >= MPPT_PERIOD_MS
  )
  {
    lastMpptTime = currentTime;

    runMppt();
  }

  if (
    mpptRunning &&
    currentTime - lastPrintTime >= 1000
  )
  {
    lastPrintTime = currentTime;

    printStatus();
  }
}

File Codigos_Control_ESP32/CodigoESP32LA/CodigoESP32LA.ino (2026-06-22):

/*
  PWM seguro para prototipo Boost con ESP32

  Pin PWM: GPIO25 / D25
  Frecuencia: 50 kHz
  Duty inicial: 0 %
  Control por monitor serie

  Comandos:
    start   -> activa PWM al 10 %
    stop    -> apaga PWM
    d 20    -> duty al 20 %
    status  -> muestra estado
*/

#include <Arduino.h>

const int PWM_PIN = 25;
const int PWM_FREQ = 50000;
const int PWM_RESOLUTION = 10;

const float DUTY_START = 10.0;
const float DUTY_MAX = 60.0;

float dutyPercent = 0.0;
bool pwmOn = false;

const int PWM_MAX = (1 << PWM_RESOLUTION) - 1;

void setDuty(float duty) {
  if (duty < 0.0) duty = 0.0;
  if (duty > DUTY_MAX) duty = DUTY_MAX;

  dutyPercent = duty;

  int dutyValue = (dutyPercent / 100.0) * PWM_MAX;
  ledcWrite(PWM_PIN, dutyValue);

  Serial.print("Duty = ");
  Serial.print(dutyPercent);
  Serial.println(" %");
}

void setup() {
  Serial.begin(115200);
  delay(1000);

  ledcAttach(PWM_PIN, PWM_FREQ, PWM_RESOLUTION);

  setDuty(0.0);

  Serial.println("PWM listo.");
  Serial.println("Comandos: start | stop | d 20 | status");
}

void loop() {
  if (Serial.available()) {
    String cmd = Serial.readStringUntil('\n');
    cmd.trim();
    cmd.toLowerCase();

    if (cmd == "start") {
      pwmOn = true;
      setDuty(DUTY_START);
      Serial.println("PWM activado.");
    }

    else if (cmd == "stop") {
      pwmOn = false;
      setDuty(0.0);
      Serial.println("PWM apagado.");
    }

    else if (cmd == "status") {
      Serial.println("----- ESTADO -----");
      Serial.print("PWM: ");
      Serial.println(pwmOn ? "ON" : "OFF");
      Serial.print("Frecuencia: ");
      Serial.print(PWM_FREQ);
      Serial.println(" Hz");
      Serial.print("Duty actual: ");
      Serial.print(dutyPercent);
      Serial.println(" %");
    }

    else if (cmd.startsWith("d ")) {
      float newDuty = cmd.substring(2).toFloat();

      if (newDuty >= 0.0 && newDuty <= DUTY_MAX) {
        pwmOn = true;
        setDuty(newDuty);
      } else {
        Serial.println("Duty fuera de rango. Maximo permitido: 60 %");
      }
    }

    else {
      Serial.println("Comando no reconocido.");
    }
  }
}

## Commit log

2026-06-20 Simulink_Matlab
    En esta carpeta se recogen todos los archivos de MATLAB/Simulink utilizados tanto en la validación del sistema original como los archivos utilizados para el prototipo.
2026-06-22 Create .gitkeep
    Simulaciones utilizadas en el apartado 4 de la memoria
2026-07-05 Add README for DC-DC Boost Converter Project
    This README provides an overview of the project, objectives, repository structure, tools used, technical content, and details about the experimental prototype.
